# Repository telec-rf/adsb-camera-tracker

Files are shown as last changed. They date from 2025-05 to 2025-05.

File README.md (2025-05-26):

# $5 DIY ADS-B Tracking Camera

A low-cost camera tracker that follows nearby aircraft using ADS-B signals and a modified pan/tilt WiFi camera. Built with Python, a Raspberry Pi, rtl-sdr, and a unipolar stepper motor driver.

---
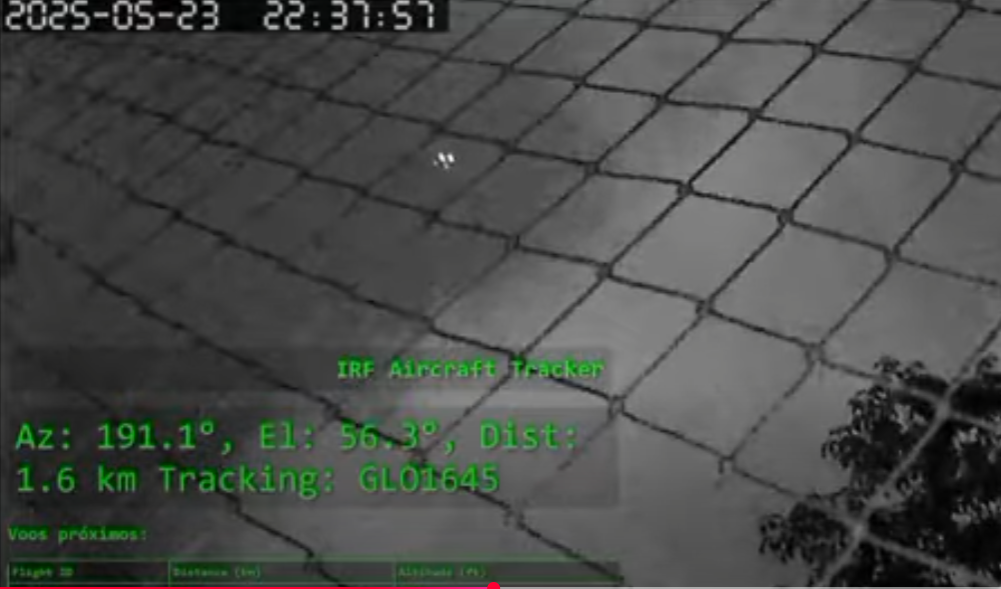
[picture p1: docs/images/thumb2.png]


🎥 [Test 1 - Tracking](https://youtu.be/_JrbGSCT38Y)   https://youtu.be/_JrbGSCT38Y

🎥 [Test 2 - Tracking](https://youtu.be/yWAEASqBwnk)   https://youtu.be/yWAEASqBwnk

## Features

* Tracks nearby aircraft in real time using local ADS-B data
* Controls pan and tilt via serial commands to an Arduino Nano
* Visual status and nearby aircraft list via Flask web interface
* Uses a cheap WiFi camera with mechanical pan/tilt capability

---

## Requirements

### Hardware

* Raspberry Pi (any model with internet and USB)
* Arduino Nano (or compatible)
* ULN2003 unipolar stepper motor driver (x2)
* Pan/tilt WiFi camera (modified for serial pan/tilt control)
* 2 stepper motors (28BYJ-48 recommended)
* ADS-B receiver (e.g. RTL-SDR + dump1090-mutability)
* Cheap wifi camera with rtsp support (refer to images)

---

## 📷 Camera Modification

Before assembling the electronics, you must **modify the pan/tilt WiFi camera** to gain direct access to the internal stepper motors.

### Steps:

1. **Open the camera housing** carefully.
2. **Identify the two unipolar stepper motors** (one for pan, one for tilt).
3. **Disconnect the motor wires** directly from the internal PCB.
4. **Route the motor wires** out of the camera using a **small hole in the bottom of the housing**.
5. **Label the wires** for pan and tilt (optional but recommended).
6. **Route power supply 5v for the camera circuit**.
7. After the modification, turn the camera all the way to the left, with it facing upwards,
 and make a mark on the body below in the direction of the center of the lens, to mark the north, this point must be aligned with the real north.

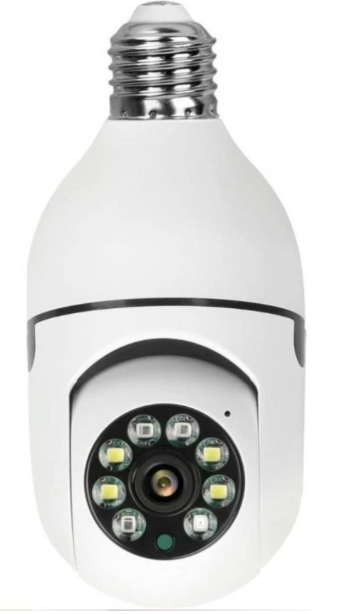
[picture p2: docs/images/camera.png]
Motor on Camera


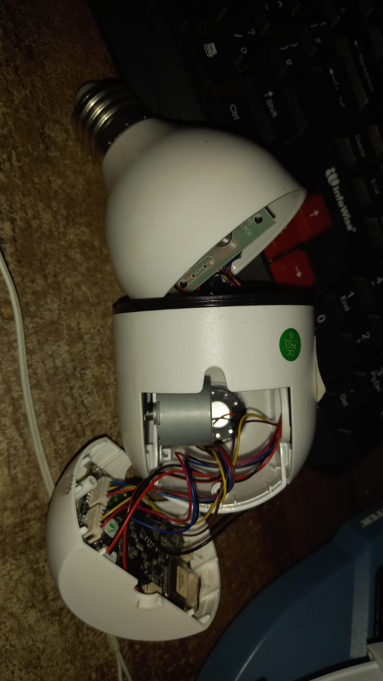
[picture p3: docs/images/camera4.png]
Motor on Camera


📸 **Refer to the photos in the `/docs` folder** for more detail.

---

## 🧩 Arduino + Driver Wiring

The circuit consists of:

* Arduino Nano
* 2x ULN2003 stepper drivers
* 2x 28BYJ-48 stepper motors
* 5V power supply ()

🖼️ Circuit schematic:

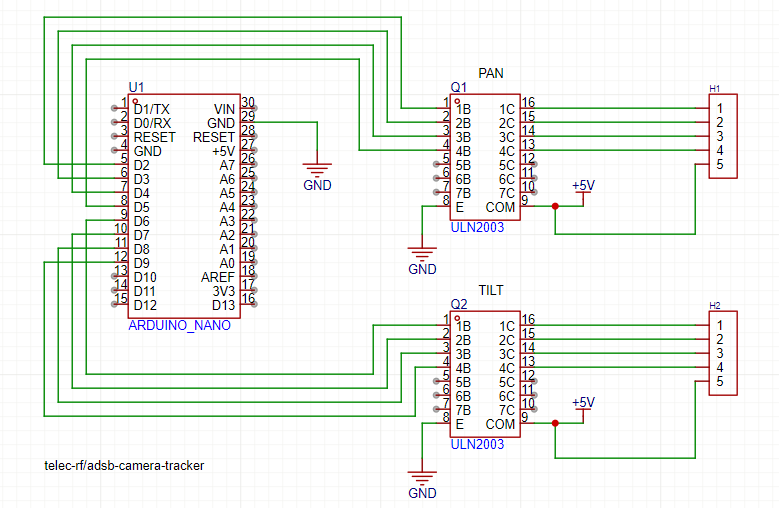
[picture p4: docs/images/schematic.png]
Schematics


* The camera has an internal AC to DC 5v power supply, remove it, it is not safe or prudent to leave it, power the camera board with 5V together

Make sure to power the motors with sufficient current, 1A is enough.

---

## Software Dependencies

Install these Python libraries:

```bash
pip3 install flask pyserial requests
````

Make sure `dump1090-mutability` is installed and running on the Pi to provide aircraft data.

---

## Exposing ADS-B Data Over HTTP

The script expects aircraft data from a JSON URL like:

```
http://<rpi_ip>:8080/aircraft.json
```

To serve this:

### 1. Create a symlink to aircraft.json

```bash
mkdir -p ~/web
ln -s /run/dump1090-mutability/aircraft.json ~/web/aircraft.json
```

### 2. Start a simple HTTP server

```bash
cd ~/web
python3 -m http.server 8080
```

### 3. Run Tracker.py
Adjust the parameters within the tracker.py file as necessary, especially the precise location of the camera and the altitude, so that the calculations are done correctly. Also pay attention to the good alignment of the camera's north, this ensures better captures.
Also adjust the address of your adsb server and also the correct serial port.

### 4. (Optional) Run it as a systemd service

Create `/etc/systemd/system/adsb-http.service`:

```ini
[Unit]
Description=Simple HTTP server for ADS-B JSON data
After=network.target

[Service]
ExecStart=/usr/bin/python3 -m http.server 8080
WorkingDirectory=/home/pi/web
User=pi
Restart=on-failure

[Install]
WantedBy=multi-user.target
```

Then enable and start:

```bash
sudo systemctl daemon-reexec
sudo systemctl daemon-reload
sudo systemctl enable adsb-http.service
sudo systemctl start adsb-http.service
```

---

## Arduino Sketch

Upload the Arduino sketch to your Nano before running the Python script.

The sketch receives serial commands like `p:120,t:30` (pan:120°, tilt:30°), interprets them, and moves the stepper motors accordingly using the ULN2003 driver.

Make sure to match your wiring (motor pins) and define pan/tilt limits accordingly.

The initial state of motor controller is 0 for pan and 0 for tilt, when it is turned on, the code calibrates the home point, and then levels the tilt

> **Note**: See the `/arduino` folder in this repository for the sketch.

---

## Web Interface

When running, access the live status page at:

```
http://<your_rpi_or_pc_ip>:5000/
```

It shows:

* Current azimuth, elevation, and distance
* Currently tracked aircraft ID
* A table of the 10 closest aircraft nearby
* Ready to use as overlay in obs studio for record or transmission

---

**"If you build one of these tracking cameras, let me know or tag me — I'd love to see it in action! 📸✈️"**

## License

GNU GPL V3. Have fun and build your own aerial tracker!

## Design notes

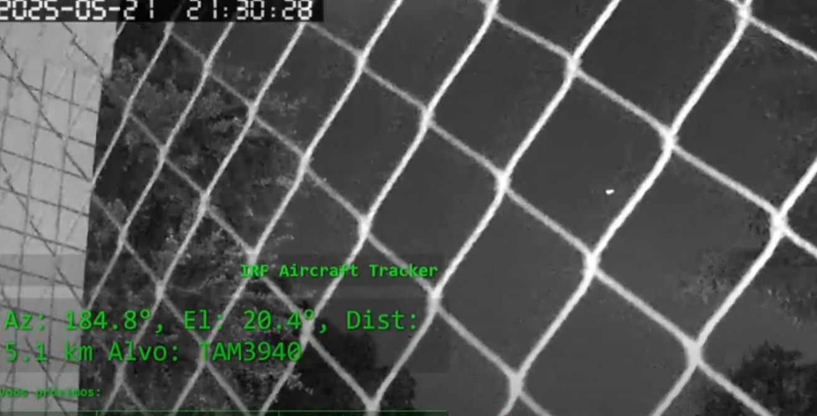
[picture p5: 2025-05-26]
docs/images/thumb1.png

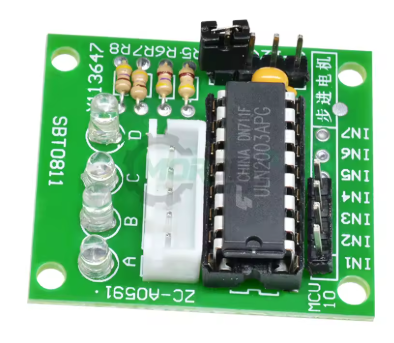
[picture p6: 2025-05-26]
docs/images/stepper_driver.png

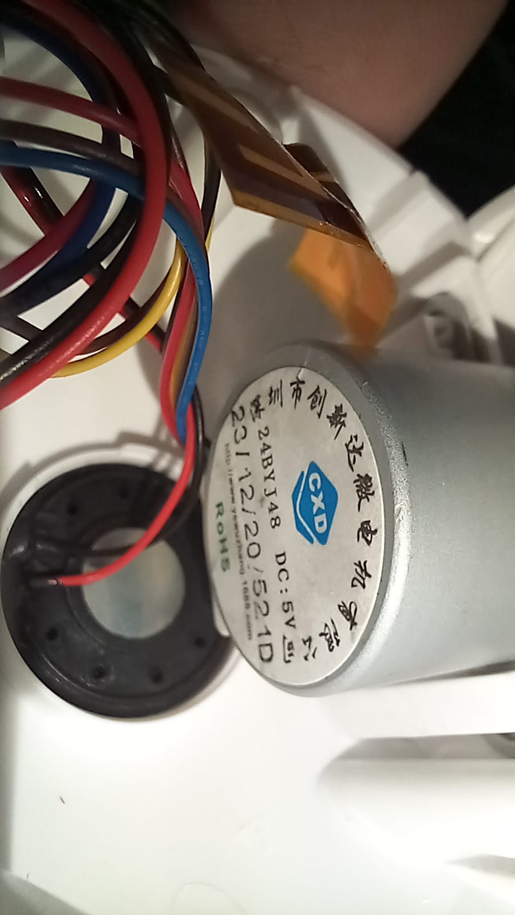
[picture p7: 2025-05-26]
docs/images/camera3.png

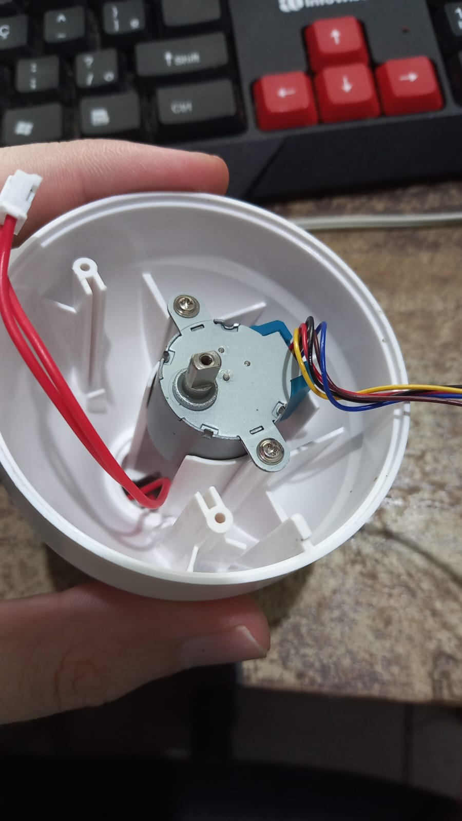
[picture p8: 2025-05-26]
docs/images/camera1.png

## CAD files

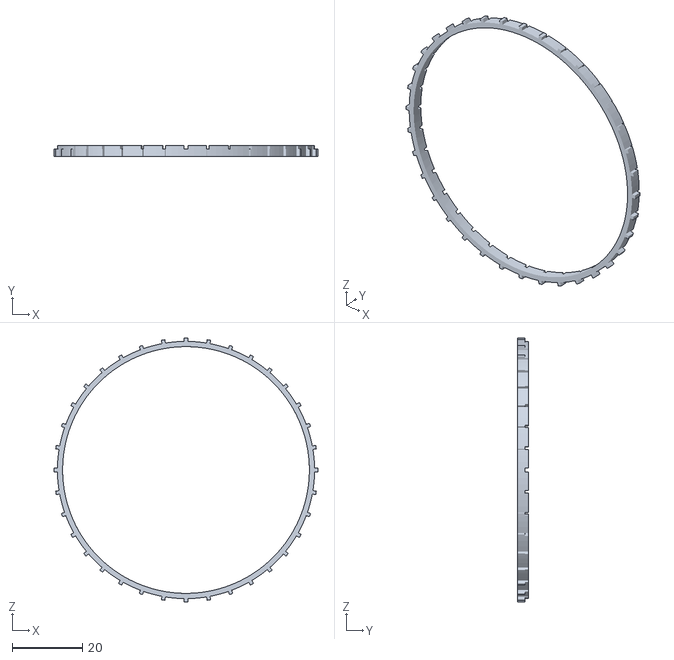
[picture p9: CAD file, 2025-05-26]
docs/calibration-disc.stl
75.0 x 3.00 x 75.0

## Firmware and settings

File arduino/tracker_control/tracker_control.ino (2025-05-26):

/*
 ==============================================================================
 Project: ADS-B Tracking and Control System
 Author: Israel Brunini Oliveira
 GitHub: https://github.com/telec-rf
 License: GNU General Public License v3.0
 Version: 0.2

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
 You should have received a copy of the GNU General Public License
 along with this program. If not, see <https://www.gnu.org/licenses/>.
 ==============================================================================
*/



// Motor de passo para PAN conectado nas portas D2 a D5
const int motor1Pins[4] = {2, 3, 4, 5}; 

// Motor de passo para TILT conectado nas portas D6 a D9
const int motor2Pins[4] = {6, 7, 8, 9}; 

// Sequência de passos (meia etapa) para 28BYJ-48 com ULN2003
const int steps[8][4] = {
  {1, 0, 0, 0},
  {1, 1, 0, 0},
  {0, 1, 0, 0},
  {0, 1, 1, 0},
  {0, 0, 1, 0},
  {0, 0, 1, 1},
  {0, 0, 0, 1},
  {1, 0, 0, 1}
};

// Motor de passo para PAN conectado nas portas D2 a D5
const int motor1Pins[4] = {2, 3, 4, 5}; 

// Motor de passo para TILT conectado nas portas D6 a D9
const int motor2Pins[4] = {6, 7, 8, 9}; 

// Sequência de passos (meia etapa) para 28BYJ-48 com ULN2003
const int steps[8][4] = {
  {1, 0, 0, 0},
  {1, 1, 0, 0},
  {0, 1, 0, 0},
  {0, 1, 1, 0},
  {0, 0, 1, 0},
  {0, 0, 1, 1},
  {0, 0, 0, 1},
  {1, 0, 0, 1}
};

const int stepDelay = 1; // Tempo entre passos (ms)

// Limite máximo de passos por eixo
const int maxPassosPan = 3940;   // Aproximadamente 350~360 graus
const int maxPassosTilt = 940;   // Aproximadamente 90 graus

// Passos por grau para cada eixo
const float passosPorGrauPan = maxPassosPan / 350.0;
const float passosPorGrauTilt = maxPassosTilt / 90.0;

int pos1 = 0; // posição da sequência do motor PAN (0 a 7)
int pos2 = 0; // posição da sequência do motor TILT (0 a 7)

float anguloPanAtual = 0.0;
float anguloTiltAtual = 0.0;

// Aplica um passo ao motor correspondente
void passoMotor(int motorPins[], int &pos, int dir) {
  pos += dir;
  if (pos > 7) pos = 0;
  if (pos < 0) pos = 7;

  for (int i = 0; i < 4; i++) {
    digitalWrite(motorPins[i], steps[pos][i]);
  }
}

// Movimento simultâneo com interpolação
void moverMotores(int passosPan, int passosTilt) {
  int dirPan = (passosPan >= 0) ? 1 : -1;
  int dirTilt = (passosTilt >= 0) ? 1 : -1;

  passosPan = abs(passosPan);
  passosTilt = abs(passosTilt);

  int maior = max(passosPan, passosTilt);
  int contPan = 0, contTilt = 0;

  for (int i = 0; i < maior; i++) {
    if ((long)contPan * maior / passosPan <= i && contPan < passosPan) {
      passoMotor(motor1Pins, pos1, dirPan);
      contPan++;
    }
    if ((long)contTilt * maior / passosTilt <= i && contTilt < passosTilt) {
      passoMotor(motor2Pins, pos2, dirTilt);
      contTilt++;
    }
    delay(stepDelay);
  }

  // Desliga bobinas após movimento
  for (int i = 0; i < 4; i++) {
    digitalWrite(motor1Pins[i], LOW);
    digitalWrite(motor2Pins[i], LOW);
  }
}

// Converte ângulos em passos e move motores
void moverGraus(float panDestino, float tiltDestino) {
  float deltaPan = panDestino - anguloPanAtual;
  float deltaTilt = tiltDestino - anguloTiltAtual;

  int passosPan = round(-deltaPan * passosPorGrauPan);   // sinal invertido!
  int passosTilt = round(-deltaTilt * passosPorGrauTilt); // sinal invertido!

  moverMotores(passosPan, passosTilt);

  anguloPanAtual = panDestino;
  anguloTiltAtual = tiltDestino;
}

void setup() {
  Serial.begin(115200);
  for (int i = 0; i < 4; i++) {
    pinMode(motor1Pins[i], OUTPUT);
    pinMode(motor2Pins[i], OUTPUT);
    digitalWrite(motor1Pins[i], LOW);
    digitalWrite(motor2Pins[i], LOW);
  }

  // Posiciona em ponto inicial arbitrário
  moverMotores(4000, 1400);
  moverMotores(0, -360);
}

void loop() {
  if (Serial.available()) {
    String comando = Serial.readStringUntil('\n');
    comando.trim();

    if (comando.equalsIgnoreCase("status?")) {
      Serial.print("p:");
      Serial.print(anguloPanAtual, 1);
      Serial.print(",t:");
      Serial.println(anguloTiltAtual, 1);
    } 
    else if (comando.startsWith("p:") && comando.indexOf(",t:") != -1) {
      int indexP = comando.indexOf("p:") + 2;
      int indexT = comando.indexOf(",t:");

      String panStr = comando.substring(indexP, indexT);
      String tiltStr = comando.substring(indexT + 3);

      float pan = panStr.toFloat();
      float tilt = tiltStr.toFloat();

      if (pan >= 0 && pan <= 340.0 && tilt >= 0 && tilt <= 90.0) {
        moverGraus(pan, tilt);
      } else {
        Serial.println("err for limit");
      }
    } 
    else {
      Serial.println("Invalid command. Use: p:XX,t:YY or status?");
    }
  }
}

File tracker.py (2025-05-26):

# =============================================================================
# Project: ADS-B Tracking and Control System
# Author: Israel Brunini Oliveira
# GitHub: https://github.com/telec-rf
# License: GNU General Public License v3.0
# Version: 0.2
# 
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


import json
import time
import math
import serial
import requests
import threading
import os
import logging
from flask import Flask, jsonify, render_template_string

# =========================
# Settings
# Configure with our precise latitude, longitude and altitude of camera (sea level to the camera)
# =========================
MY_LAT = 0.0
MY_LON = 0.0
MY_ALT = 30  # meters of camera above sea

DIST_MAX_KM = 9 # Target max distance to capture
ALT_MAX = 9000  # Max altitude to tracking in feets

LISTA_DIST_MAX_KM = 50   # Max distance of html overlay
LISTA_ALT_MAX = 30000    # Max altitide of html overlay


ADSB_IP = "192.168.100.2"
ADSB_PORT = 8080


SERIAL_PORT = 'COM3'
# ------ END Settings ------- #


SEND_INTERVAL = 0.8

BAUDRATE = 115200
CAMERA_PAN_MAX = 340.0
CAMERA_TILT_MAX = 90.0

JSON_URL = f"http://{ADSB_IP}:{ADSB_PORT}/aircraft.json"

# =========================
# VARIÁVEIS GLOBAIS
# =========================
status_data = {"az": 0, "el": 0, "dist": 0, "alvo": "N/A"}
voos_proximos = []

# =========================
# FUNÇÕES AUXILIARES
# =========================
logging.getLogger('werkzeug').setLevel(logging.ERROR)

def haversine(lat1, lon1, lat2, lon2):
    R = 6371  # km
    phi1 = math.radians(lat1)
    phi2 = math.radians(lat2)
    dphi = math.radians(lat2 - lat1)
    dlambda = math.radians(lon2 - lon1)
    a = math.sin(dphi / 2) ** 2 + math.cos(phi1) * math.cos(phi2) * math.sin(dlambda / 2) ** 2
    c = 2 * math.atan2(math.sqrt(a), math.sqrt(1 - a))
    return R * c

def calc_az_el(lat, lon, alt):
    dist_km = haversine(MY_LAT, MY_LON, lat, lon)
    dist_m = dist_km * 1000
    delta_alt = alt - MY_ALT
    az = math.degrees(math.atan2(math.radians(lon - MY_LON), math.radians(lat - MY_LAT)))
    az = (az + 360) % 360
    el = math.degrees(math.atan2(delta_alt, dist_m))
    el = max(0.0, min(el, CAMERA_TILT_MAX))
    return az, el, dist_km

def format_command(pan, tilt):
    pan = min(pan, CAMERA_PAN_MAX)
    tilt = min(tilt, CAMERA_TILT_MAX)
    return f"p:{pan:.1f},t:{tilt:.1f}"

def escolher_alvo(dados):
    aeronaves = dados.get("aircraft", [])
    melhores = []
    lista_info = []

    for ac in aeronaves:
        if "lat" in ac and "lon" in ac and "altitude" in ac:
            seen = ac.get("seen_pos", 9999)
            alt = ac.get("altitude", 0)
            lat = ac["lat"]
            lon = ac["lon"]
            dist_km = haversine(MY_LAT, MY_LON, lat, lon)

            # Preenche lista informativa
            if seen < 60 and alt <= LISTA_ALT_MAX and dist_km <= LISTA_DIST_MAX_KM:
                lista_info.append({
                    "flight": ac.get("flight", ac.get("hex")),
                    "dist": round(dist_km, 1),
                    "alt": alt,
                    "seen": seen
                })

            # Preenche candidatos para rastreamento
            if seen < 10 and alt <= ALT_MAX and dist_km <= DIST_MAX_KM:
                melhores.append((dist_km, ac))

    lista_info.sort(key=lambda x: x["dist"])
    global voos_proximos
    voos_proximos = lista_info[:10]

    return melhores[0][1] if melhores else None

# =========================
# FLASK APP
# =========================

app = Flask(__name__)

@app.route("/")
def index():
    return render_template_string("""
    <html>
    <head>
        <meta charset="utf-8">
        <title>Status Ao Vivo</title>
      <style>
    body {
        background: black;
        color: lime;
        font-family: monospace;
        text-shadow: 2px 2px 4px black;
    }

    h1, .big, table, th, td {
        background-color: rgba(0, 0, 0, 0.3); /* Fundo preto com 50% de opacidade */
    }

    h1 {

    text-align: right;
    margin-right: 10px;
        font-size: 2em;
        padding: 10px;
        border-radius: 8px;
        text-shadow: 2px 2px 4px black;
    }

    .big {
        font-size: 3em;
        padding: 10px;
        border-radius: 8px;
        text-shadow: 2px 2px 4px black;
    }

    table {
        border-collapse: collapse;
        width: 100%;
        color: lime;
        margin-top: 20px;
        text-shadow: 1px 1px 3px black;
        border-radius: 8px;
        overflow: hidden;
    }

    th, td {
        border: 1px solid lime;
        padding: 5px;
        text-align: left;
        text-shadow: 1px 1px 3px black;
    }
</style>

    </head>
    <body>
        <h1>IRF Aircraft Tracker</h1>
        <div class="big" id="status">Carregando...</div>

        <h2>Voos próximos:</h2>
        <table>
            <thead>
                <tr><th>Flight ID</th><th>Distance (km)</th><th>Altitude (ft)</th></tr>
            </thead>
            <tbody id="lista">
                <tr><td colspan="4">Carregando...</td></tr>
            </tbody>
        </table>

        <script>
        function atualizar() {
            fetch("/status")
                .then(res => res.json())
                .then(data => {
                    document.getElementById("status").innerText = 
                        `Az: ${data.az}°, El: ${data.el}°, Dist: ${data.dist} km       Tracking: ${data.alvo}`;
                });

            fetch("/alvos")
                .then(res => res.json())
                .then(data => {
                    const tbody = document.getElementById("lista");
                    tbody.innerHTML = "";
                    for (let ac of data) {
                        tbody.innerHTML += `<tr>
                            <td>${ac.flight}</td>
                            <td>${ac.dist}</td>
                            <td>${ac.alt}</td>
                            
                        </tr>`;
                    }
                });
        }
        setInterval(atualizar, 500);
        atualizar();
        </script>
    </body>
    </html>
    """)

@app.route("/status")
def status():
    return jsonify(status_data)

@app.route("/alvos")
def alvos():
    return jsonify(voos_proximos)

# =========================
# LOOP PRINCIPAL EM THREAD
# =========================
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

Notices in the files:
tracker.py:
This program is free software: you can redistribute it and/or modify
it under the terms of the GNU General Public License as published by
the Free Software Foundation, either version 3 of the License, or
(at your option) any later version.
